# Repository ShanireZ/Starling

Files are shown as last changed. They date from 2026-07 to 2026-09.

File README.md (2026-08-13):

# Starling






Starling v2 是面向 Suzuki GSX250R 车身侧板的电子百叶进气口（“鳃口”）原型：固定框承风、多片叶片由一个舵机联动，开口朝车头迎风，并随车速张合。

## 当前状态

原型一号已经形成可审查的设计包，但尚未完成上板或实车验证：

- [立项文档](docs/charter.md)记录 v2 的范围、失效保护和安全边界。
- [原型一号规格](docs/prototype-v1.md)包含 BOM、接线、台架验证顺序和控制逻辑。
- [参数化 CAD](cad/starling_v1.scad)及其 [打印/装配说明](cad/README.md)是机构的唯一 CAD 来源；`cad/dist/` 为打印交付包。
- [固件骨架](firmware/starling/starling.ino)面向 ESP32 DevKit（WROOM-32），定义了皮托压差测速、舵机控制、被动记录和 USB/蓝牙配置边界；源码明确标注为尚未上板编译验证的骨架。

## 3D 机构演示

[gsx250r-vreal.html](proto/gsx250r-vreal.html) 是唯一现行 3D 演示。可通过本地静态 HTTP 服务器从仓库根目录打开。页面用滑杆模拟车速和百叶开度，并可拖入其他 `.glb`/`.gltf` 模型。页面中的气流效果是机制演示，**不是 CFD 或性能验证**。

## 项目约束

- 设计铁律和当前状态见 [AGENTS.md](AGENTS.md)。
- 断电时机构应由弹簧回到闭合位置；上路前须完成台架、封闭场地和当地法规自查。

## License

本项目自有的代码、文档与素材采用 [GNU General Public License v3.0](LICENSE) 发布。

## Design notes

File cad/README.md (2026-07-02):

# cad/ — 原型一号机构(v0.1 台架版)

> **唯一 CAD 真相 = [`starling_v1.scad`](starling_v1.scad)**(OpenSCAD 参数化源码);`stl/` 全部由源导出,勿手编;`preview/` 为渲染验证图。
> 装 [OpenSCAD](https://openscad.org) 后打开 .scad 即可改参数 → F6 渲染 → 导出 STL(文件底部 `PART` 变量选零件)。
>
> **代打交付包 = [`dist/`](dist)**:带数量的 STL + [`dist/下单说明.txt`](dist/下单说明.txt)(工艺/材料/公差逐件备注)+ 一键上传的 `starling-print-v0.2-pa12.zip`。给打印农场只发 dist,勿发 stl/。
>
> **材料路线(2026-07-02 owner 拍板)**:跳过 PLA 台架批,**直接粉末尼龙一步到位**——MJF/SLS **PA12**(叶片勿加 CF,薄壁要韧性)、框/支架可升 **PA12-CF**;原"台架 PLA → 装车 PETG"路线作废。dist 的 STL 按粉末工艺 `HOLE_COMP=0.1` 导出(FDM 备选须回源码改 0.2 重出);下表"打印姿态/填充"仅对 FDM 备选工艺有意义,粉末工艺无支撑/填充概念。**连带变更:尼龙粘不住 502/CA,装配用胶一律改环氧 AB(粘接面打毛)。**

## 打印清单

| 零件 | 数量 | 打印姿态 | 填充 | 备注 |
|---|---|---|---|---|
| `frame` 固定框 | 1 | 前脸朝下平放 | 30% | 前脸内圈有 3.5mm 悬檐(可加支撑或接受轻微垂坠);轴孔为水平小孔允桥接,打完用 3mm 钻/圆锉轻通 |
| `blade` 叶片 | **4** | 凸面朝下平放 | 100%(薄件) | **两侧翼下需支撑**(弧形底非平面);背脊轴槽朝上,槽内勿生成支撑 |
| `crank` 曲柄 | **4** | 平放 | 100% | 受力小件,实心打 |
| `linkbar` 拉杆 | 1 | 平放 | 100% | |
| `servo_bracket` 舵机支架 | 1 | 板面朝下平放 | 60% | |
| `stand` 台架座 | 1 | 如模型姿态 | 20% | 台架专用,装车不用 |

层高 0.2 / 壁 3 圈(仅 FDM 备选适用)。

## 金属件下料(免焊:剪/锯 + 环氧 AB 胶)

| 料 | 下料 | 用途 |
|---|---|---|
| Ø2 不锈钢轴 | **4 段 × 125mm** | 叶轴(300mm 棒 ×2 根够用) |
| 黄铜管 内2外3 | **8 段 × 6mm** | 轴套,压入框两侧柱孔 |
| M2 螺丝 | 4 颗(≈8mm) | 曲柄销:自攻进曲柄销孔,杆身穿拉杆孔 |
| M2 球头拉杆 | 1 套(杆 ≈25mm 起配) | 舵机臂(8mm 孔位)↔ 拉杆下端孔 |
| M3 自攻 | 2 颗 | 框下双耳 → 台架座立柱 |
| 小扭簧 | 1 只(试配) | 套顶叶轴:一脚插框右柱 Ø2 锚孔,一脚顶曲柄——预紧朝闭合 |

## 装配顺序(台架)

1. 框轴孔压入 8 只黄铜套(紧则用 HOLE_COMP 调大重打框,勿硬敲裂框);
2. 钢轴卡进叶片背脊槽 + 环氧 AB 胶(粘接面砂纸打毛;尼龙粘不住 502/CA),居中(两端各露 ≈12.5mm);
3. 叶片连轴从框内穿入两侧轴套;右侧露出端压上曲柄(过盈 + 环氧胶),**四只曲柄臂必须同角度**(装配时把叶片全部立到竖直位再粘曲柄);
4. M2 螺丝把四只曲柄销接到拉杆四孔(自攻进曲柄,拉杆孔为松孔,能自由转动);
5. 舵机装支架窗口(自带自攻钉),支架用 2×M3 挂框右柱(竖槽可上下微调);
6. 球头拉杆连舵机臂(取 8mm 孔位)与拉杆下端孔,**用易拉夹/球头螺纹把长度调到:舵机中位 ≈ 叶片 50° 半开**;
7. 顶叶轴套扭簧(预紧朝闭合),断电手感验证:松手全组弹回闭合;
8. 框挂台架座(下双耳 M3 自攻进立柱),整机通电跑 `test` 命令扫角。

## 行程与固件映射

- 机械行程:**闭合 = 10°**(微倾使相邻叶鳞片式搭接,不是 0° 纯竖直——纯竖直相邻叶尖会干涉)→ **全开 = 90°(水平)**;
- 固件把 0-100% 开度映射到舵机脉宽 `us0..us90`:**台架标定** `us0` = 叶片抵到闭合位、`us90` = 水平全开位(`set us0 / set us90` + `save`),CLOSED_DEG 的 10° 偏置被标定自然吸收,固件无需改。

## ★ 到货必须卡尺复测的参数(改完重渲重打)

| 参数 | 现值(估) | 说明 |
|---|---|---|
| `SV_HOLE_SPAN` | 34.0 | 舵机两安装孔中心距(**最关键**) |
| `SV_BODY_L / SV_BODY_W` | 28.6 / 13.2 | 舵机体长宽(窗口配合) |
| `SV_AXIS_OFF` | 9.7 | 输出轴距体端偏移 |
| `BUSH_OD / SHAFT_D` | 3.0 / 2.0 | 黄铜套外径 / 钢轴径 |
| `HOLE_COMP` | 源码默认 0.2(FDM);**dist PA12 批以 0.1 导出** | 压入过紧 → 调大 0.1 重出;过松 → 调小 |

## 已验证(2026-07-02)

- 6 件 STL 全部水密(trimesh `is_watertight=True`)、包围盒与设计值一致;
- 正交前视:闭合(10°)四叶满窗遮蔽 / 全开(90°)水平露缝([preview/front_10.png](preview/front_10.png) / [front_90.png](preview/front_90.png));
- 曲柄-拉杆平行四边形联动:侧视 90° 时曲柄水平与拉杆重合、拉杆随销圆弧平移,运动学正确;
- 叶尖扫掠 ±28.9mm vs 内腔 ±30mm,间隙 1.1mm(此项曾按 56 高设计会刮壁,已改 60)。

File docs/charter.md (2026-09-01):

---
type: charter
title: Starling v2 立项文档
---

# Starling v2 立项文档

> **一句话**:装在 GSX250R **车身侧板(车把下整流罩)**上的一对**电子百叶进气口("鳃口")**(固定框 + 联动叶片),**开口朝车头迎风**,随车速开合——越快开得越大,像**张鳃呼吸**纳入迎面气流。**看得见的动态造型件;开口通透后迎风纳气,带来附带的气流 / 散热收益(温和,非主目标)。**

立项日期:2026-06-25 · 名称沿用 Starling(v1 同名项目已废弃重启)

---

## 0. 为什么重启:v1 的教训

v1(摩托车主动空气动力学系统)流产,四个失败点其实是同一个病根的四张脸——**成本前置、收益后置,而收益天花板本来就低**:

| v1 失败点 | 实质 |
|---|---|
| 设计过于复杂,逐渐流产 | 成本无限后拖,从未产出可用切片 |
| 成本 ≫ 收益(仅很小提升) | **真正死因**:250 摩托 <100km/h,主动气动的下压力收益微乎其微 |
| 结构复杂、不便调试观察 | 烧钱过程中看不见盈亏 |
| 过于专业 | 锁死在一个人脑子里,无人能验 |

**复杂本身不是罪,复杂配不上收益才是。** v2 由此立下两道闸:

1. **立项前给收益封顶** —— 性能收益有限,故**以造型 / 动态炫酷为主目标**;鳃口迎风纳气带来的气流 / 散热只当**附带温和收益**,把成本对齐"炫酷"这个可达又可观察的价值,不为微小性能堆复杂度。
2. **第一周就要有看得见的纵切片** —— 用最小可观察实物验证,而非建几个月才发现不值。

---

## 1. 项目身份

- **名称**:Starling(沿用并重释义——椋鸟 / 凤凰,展翅母题)
- **平台**:Suzuki **GSX250R**(单车型起步,非通用支架)
- **形态(2026-06-25 大改 → 百叶式;2026-06-28 定位侧板 + 开口朝车头迎风)**:**车身侧板(车把下整流罩)**上一对**电子百叶进气口("鳃口")**——一个**固定的 U / 矩形结构框**(内凹、NACA 式观感),框内一组**多片联动百叶**,**开口朝车头迎风**。低速齐平闭合,高速叶片张开露缝(战斗机 / F1 多段开缝层叠面的样子)。
- **行为**:**速度越快 → 开度越大**(MCU 按速度驱动百叶角度);开口朝前,张开时像「张鳃呼吸」纳入迎面气流。
- **机构**:固定框承受风载;百叶 = **一个舵机 + 一根连杆带动多片 = 1 个真实自由度**(汽车主动进气格栅 / 空调出风口的成熟做法)。
- **气动姿态(无害优先,收益封顶)**:① **开口朝车头迎风**,低速齐平闭合(最低阻),高速张开像「张鳃呼吸」纳入迎面气流;② 固定框包住叶片边缘(少抖振 / 哨音);③ **后侧通透**(去死后壁、叶片张开气流可从前侧穿过进喉道→入车体内部·借真进气口的观感),**带附带的轻度进气 / 散热作用**,但**不做重型工程化涵道 / 冷却系统**(无独立 airbox·只求开口通透的纳气观感与轻度穿流);高速张开会有少量增阻(迎风口纳气),在 <100km/h、小开口下视为**无害可接受**;**性能非主目标——收益封顶,不为它堆复杂度。**
- **无灯光**:视觉价值 = 这套随速度开合的**动态** + 造型本身。

---

## 2. 定位与价值(收益封顶)

- **价值锚点**:视觉 / 动态炫酷("展翅感"),外行一眼能看懂
- **性能非主目标(收益封顶)**:迎风纳气有附带气流 / 散热收益,但不做气动调优、不堆性能向复杂度
- **场景**:100km/h 以内的日常骑行
- **ROI 闸门**:任何"为多一点性能 / 下压力"的复杂度,默认砍掉

---

## 3. 控制架构(防战线蔓延的生死线)

- **实时控制 100% 板载自包含**:MCU + 传感器,本地决定翼面开度
- **外部连接(蓝牙或有线)只做两件事**:① 配置(模式 / 参数) ② 数据采集与回传
- **外部端(手机 / PC / 网页)不参与实时控制**
- **无云、无 OTA、无跨学科集成**

---

## 4. 设计铁律(v1 四大死因的对策)

1. **收益封顶** — 主价值是造型 / 动态炫酷;迎风纳气的气流 / 散热是**附带温和收益、非目标**;砍掉一切"为性能"的显著复杂度。
2. **第一周可观察纵切片** — 先做出"翼面随某个输入张合"的能看见的最小原型。
3. **单人可造、可调、可调试** — 不引入需专家 / 多人才能维护的结构。
4. **禁战线蔓延** — 无 App 实时控制、无云、无 OTA、无应变片性能反馈链、无多学科集成计划。
5. **外行可读** — 不懂的人看一眼就明白"它随速度展翅,很酷"。

---

## 5. 范围

### ✅ 做(In)
- **机械**:固定 U / 矩形框(兼车头安装支架)+ 多片联动百叶 + 单舵机连杆
- **电子**:板载 MCU + 测速传感 + 供电 + 舵机驱动
- **软件**:板载实时控制逻辑(速度 → 开度)+ 极简配置 / 数据接口(蓝牙或有线)

### ❌ 不做(Out — 明确放弃,守住边界)
- 主动下压力优化 / 闭环气动调参 / 借襟翼追升力
- **重型工程化涵道 / 主动冷却系统**(开口通透有轻度穿流与附带散热,但不做独立 airbox / 热管理)
- 配套 App 实时控制 / 云遥测 / OTA
- 应变片性能反馈链 / 五学科集成计划(v1 的坟墓)
- 灯光

---

## 6. 待裁决(Open Questions — 下一轮立项逐项拍板)

> 刻意保持精简(v1 曾有 28 项启动自检清单——那本身就是病征)。下面是真正卡住设计的少数硬议题。

| # | 议题 | 为什么是硬议题 |
|---|---|---|
| ✅ ~~OQ-1~~ | **作动方式 = MCU 驱动百叶**(舵机按车速设开度) | 已裁决 2026-06-25,随百叶式微调:固定框承受风载、舵机只转小叶片(几乎不吃力);失效保护 = 断电弹回齐平闭合。第一台先做"手动 / 单舵机开合"最小验证 |
| ✅ ~~OQ-2~~ | **平台 = Suzuki GSX250R**(单车型起步) | 已裁决 2026-06-25 |
| ✅ ~~OQ-8~~ | **原型 = 3D 打印**(PLA/PETG;定形后再谈碳板 / 注塑) | 已裁决 2026-06-25 |
| ✅ ~~OQ-9~~ | **形态 = 百叶进气口**(固定 U/矩形框 + 多片联动百叶;低速齐平、高速张开露缝;NACA 内凹观感,非真涵道。**2026-06-28:落车身侧板、开口朝车头迎风**) | **2026-06-25 大改**:由"3 片式折叠成平面"转为百叶式(见 §1)。折叠方案因承风差、舵机顶不住、易抖振而放弃;开口由侧向改迎风见 §7(2026-06-28) |
| ✅ ~~OQ-M~~ | **机构自由度 = 1**(固定框 + 一个舵机经连杆联动全部叶片) | 已裁决 2026-06-25。百叶式把头号复杂度风险一举压到 1 自由度,固定框承风 |
| ✅ ~~OQ-3~~ | **供电 = 先独立电池、后取车电**(原型用充电宝/小 Li 包·零侵入易拆;定形后改带保险丝的附件取车 12V) | 已裁决 2026-06-28。阶段化:第一周可观察优先零侵入 |
| ✅ ~~OQ-4~~ | **测速来源 = 气流压差(皮托管 + 压差传感)** | 已裁决 2026-06-28。板载自包含、不碰车辆系统;主题最契合——迎风口对真实迎面动压开合 |
| ✅ ~~OQ-5~~ | **开度-速度 = 阈值-斜坡曲线 + 失效保护**(低速齐平闭合→过阈值线性张开→高速全开;**全开角硬上限 + 断电弹簧弹回闭合 + 滞回防抖**) | 已裁决 2026-06-28。阈值/斜率具体数值待原型实测调 |
| ✅ ~~OQ-6~~ | **数据 = 丰富采集**(速度/开度/舵机 + 温度/振动/IMU 等),本地存储(+离线回传),**用途 = 为后续版本与其他产品积累数据基础**(R&D 数据集·非本产品性能调优) | 已裁决 2026-06-28。★**守边界(防 v1 性能反馈链复发)**:纯**被动记录·不进实时控制闭环**(实时控制仍只用皮托速度→开度·板载自包含);采数据是副产物非主线、不借此把传感/学科铺开;本地为主、无云实时遥测。落在 §3 允许的"数据采集与回传"内 |
| ✅ ~~OQ-7~~ | **连接 = 有线 USB + 蓝牙 都要**(有线为主:配置/下数据;蓝牙仅免拆配置)。**两者都严守 §3:仅配置 + 数据采集,不碰实时控制、无云、无 OTA** | 已裁决 2026-06-28。蓝牙加 BT 模块但锁死在"非实时控制"边界内防战线蔓延 |
| ✅ ~~OQ-10~~ | **安全/法规 = 低姿态 + 失效闭合 + 本地自查**(工程:低凸出 / 无尖锐边 / 断电弹回闭合静止齐平 / 限位防过张;法规:owner 按当地车检自查突出物·灯光遮挡·噪音;上路前先封闭场地验证) | 已裁决 2026-06-28。鳃口落**侧板**(非车头正前伸入行人路径)风险面更低 |

---

## 7. 状态

- **2026-06-25**:v2 立项启动。地基 3 决策锁定——形态 / 控制 / 名称(沿用 Starling)。仓库与本 charter 建立。
- **2026-06-25**:连续裁决 OQ-1/OQ-2/OQ-8/OQ-9 + 气动逻辑(早先为 3 片式折叠成平面方案)。
- **2026-06-25(形态大改 → 百叶式,已锁定)**:经多轮 3D 推演,**放弃 3 片折叠方案,转为"固定框 + 多片联动百叶"进气口**。理由:折叠方案承风差、舵机顶不住、易抖振。新方案 = **1 自由度**(OQ-M 解决)、固定框承风、低速齐平 / 高速**前缘下斜**张开(消除升力)、**借涵道 / NACA 观感但不做真穿流**。3D 机构示意见 `proto/wing-3d.html`。
- **2026-06-25(暂停于此)**:百叶版形态完整、已存档推送(`proto/wing-3d.html`,commit `40b6733`)。气流方向已厘清——**百叶前缘朝下、正面气流上偏 → 车身微下压力(绝不升力)**;该下压力很小,**不追求**。owner 先歇,后续按 §8 继续。
- **2026-06-26(§8 高仿真第一稿落地)**:owner 拍板"继续推进"→ 新建 `proto/gsx250r-vreal.html`,把示意方块升级为**贴近 GSX250R 车头比例的体块**(全整流罩鼻锥 + 竖排双头灯 + 熏黑风挡 + 前挡泥板 + 前叉 + 前轮/碟盘 + 后视镜),并把**一对百叶进气口落位**到车头两侧真实位置:固定框 + 4 片**有弧度翼型薄片**联动、内凹深腔(借 NACA 观感)、低速齐平 ↔ 高速张开。交互保留(车速→开度滑杆 / orbit / 5 视角预设 / 自动播放)。**验证**:已起静态服务器在真实浏览器引擎中加载——THREE 加载、WebGL 上下文 OK、脚本无异常跑通、滑杆 0→35%→70%→全开→0 readout 正确联动;唯一坑=three.js 的 `Object3D.position` 只读,`Object.assign(mesh,{position})` 必抛 TypeError(已改用 `at()` 助手 `.position.set()`)。**注**:WebGL + 连续 rAF 致无头截图超时,故只做了 DOM/执行级验证;**视觉/比例/叶形美感请 owner 在真实浏览器里眼校**(本稿定位为"比例落位稿",叶形与车漆细节为下一轮精修)。
- **2026-06-26(owner 定角度规格)**:**初始(0 km/h)= 叶片竖直贴面**(0°,齐平封口)、**张开到顶 = 45°**。滑杆 0°→45° 映射。注:"越快开度越大"的**速度→角度曲线属 OQ-5**(慢速是否已到 45°、高速是否更平,待定)。
- **2026-06-26(owner 草图定开合方式:鳃片外掀,非内缩)**:据 owner 手绘 —— 张开时叶片**绕上缘铰链向外掀起、下缘凸出车体表面**(像鳃片 / scoop 张开),露出身后深腔;**不是**往里缩进风道(初版做反)。迎风的外/上表面把正面来风向上导出 → 下压力。代码探针实测全开:下缘 z 由 0.008→**0.107(凸出)**、迎风外法线 Y=**0.707(朝上)**、`protrudesOut & deflectsUp = true`;闭合则前后缘等 z(竖直贴面、中性)。
- **2026-06-26(owner 反馈两项修正,已改)**:第一稿有两处与昨日结论不符,已修——① **百叶开合方向初版做反了**(初版张开是前缘上抬 → 会把风下导=升力,危险)。现已修正为**前缘(下缘)下斜、后缘上抬**:迎面风打在叶片上表面被**向上导出 → 微下压力(绝不升力)**,与 §1/§8 文字一致。代码探针实测开启时下缘在前/在下、上缘在后/在上(`frontLowerAndForward=true`,数值验证非靠截图)。② **风道太浅(薄薄一层)→ 已加深**:风道深度 0.16→**0.42**,内凹腔由后壁 + 上/下/左/右四面内壁组成真实深腔,叶片上缘后掀进风道。
- **2026-06-26(owner 反馈:动效看不清 + 车体太简略 → 转真实建模)**:owner 拍板**车体走路线 A = 导入真实 glTF 模型**。已落地:① **glTF 加载器**(`THREE.GLTFLoader`,jsdelivr UMD):把 `.glb/.gltf` **拖进画面**即加载、或 `?model=URL`;自动缩放居中落地、隐藏占位体块;真车未到位时显示占位体块。**已用 Khronos 样本 GLB 远程验证加载/解析/auto-fit 全通**(`mstatus→已加载`,无报错)。② **百叶动效清晰化**:进气口加大、亮银蓝叶片 + **橙色自由(下)缘描边**(看清哪条缘在动)、深腔更黑拉对比、新增「🔍 进气口特写」视角(默认朝向·NDC 实测右进气口居中 x=0)、滚轮缩放、自动播放放慢 + 两端停顿并默认开启。③ 进气口已独立成 `intakeRig` 组(换真车后整体重定位)。**待 owner**:提供 / 批准一个 GSX250R(或运动摩托)`.glb`(Sketchfab 可下载+CC 过滤,或任意 .glb 拖入);搜索未见干净 CC0 直链 GSX250R。
- **2026-06-26(owner:完全仿真整车 → 收集资料 + 按真实尺寸重建)**:owner 要"车身 / 风道比例 / 后轮 / 完全仿真 GSX,先收集资料建模"。① **收集资料** → 新建 `docs/gsx250r-reference.md`(官方实测:总长 2085 / 宽 740 / 高 1110 / 轴距 1430 / 座高 790 mm;前胎 110/80-17→外半径 304、后胎 140/70-17→外半径 314;17" 十辐;整流罩散热气流逻辑给「鳃口」落位依据)。② **按真实尺寸重建整车**(SPEC 驱动,1 unit=1 m):前后两轮(正确半径/胎宽/轴距)+ 前叉/后摇臂/避震/引擎/排气/油箱/座/尾段/全包整流罩/竖排双头灯/熏黑风挡/前后挡泥板/后视镜/把手;进气口按真实比例落上侧整流罩。**实测对齐**:整车内禀 高 **1.11 m(=真车 1.110 ✓)**、长 **2.05 m(真车 2.085)**、轴距 1.43、落地 y=0;整车默认视角全可见居中、进气口特写 NDC≈(0,0) 居中、百叶机构 `protrudesOut & deflectsUp=true`、无报错。**诚实边界**:手写 three.js = **风格化 CG 非照片级**;照片级仍需拖入真 .glb(加载器已就绪)。
- **2026-06-26(owner:风洞模拟效果,务必真实)**:**诚实边界已言明**——真 CFD(解 N-S/网格/算力)在单文件网页做不到、也超出"视觉件非性能件"的边界;遂做**风洞式气流可视化(示意,非 CFD 解算)**:启发式流场 = 来流 -Z + 车体绕流(Rankine 源-汇)+ 百叶上导(每侧进气口局部上向速度随开度增强);渲染 30 条静态流线(暖色=被明显上导)+ 1400 粒子(live 烟流)+ 测试段框,「🌫 风洞气流」按钮切换、随车速滑杆联动。**数值验证**:右进气口上游流线最高 y 由闭合 1.004 → 全开 **1.169**(+16.5cm 上导),如实呈现"百叶张开→迎面风上导=下压力",随开度增强;WebGL OK 无报错。界面明确标注"非 CFD、仅机制演示非性能验证"(守住不拿气动论证存在意义的红线)。
- **2026-06-26(气动取舍 owner 拍板 B:高速放平低阻,不要下压力)**:讨论后明确——百叶「斜着导流出下压力」与「放平羽化低阻」是**相反叶片角度,不可兼得**;且下压力本就可忽略(~10–15N/<1%车重)、对操控无实感。**owner 选 B**:全开角由 -45° 改 **-90°(水平/顺气流/羽化=低阻通风口)**,高速主打低阻、明确**放弃下压力叙事**。风洞流场同步:偏流强度 = `sin(开度×π)`(0° 与 90° 皆 0、~45° 最大)→ 全速放平流线**顺流穿过不再上挑**。数值验证:右进气口流线最高 y 闭合 1.004 / 中途 1.169 / **全速 1.004(0 偏流=低阻)**。注:阻力最低其实是**闭合齐平**态,任何张开都比闭合多一点阻;"水平"是张开姿态里最省的。
- **2026-06-26(路线 A 落地:真实车体模型接入 + 鳃口落位)**:owner 经 Edge 的 Claude 浏览器插件让我直连看渲染;确认手搓方块车=Minecraft 感天花板,**走真 .glb**。我用浏览器在 Sketchfab 搜到并由 owner 下载 **"Sports Bike" by Futurealiti(CC-BY-4.0)** 放进 `res/sports_bike`(scene.gltf+bin+textures);加载器默认加载它(经静态服务器·`?model=` 可换),`fitModel` 自动缩放居中落地、隐藏占位方块。**鳃口落位**:浏览器实测调出 `GILL_ON_BIKE={iy:0.80,iz:0.78,scale:0.48,spread:0.19,ry:0.45}`(+z=车头),`showModel` 加载后自动把 `intakeRig` 落到前整流罩侧面(headlight 侧颊)。视觉降噪:头灯改小六角、百叶哑光中灰、主光降一档。**已加 CC-BY 署名**(页面 + README + license.txt)。**效果=终于像真车 + 鳃口在前整流罩侧**(虽略凸出曲面)。
- **2026-06-28(修头号缺陷:鳃口被车壳遮挡 → 射线吸附落位)**:owner 反馈「鳃口被车辆模型遮住」。**真因实测**(Edge 的 Claude 浏览器插件 + 本地静态服直连):上一版「收紧落位」(commit `dffdae1`)把鳃口推到 bike-local x≈±0.13,而整流罩**外表面**在该高度位于 x≈±0.25 → 鳃口整体埋进车壳约 0.1m,被红漆整流罩完全遮挡。**改为射线吸附 `snapGillsToModel`**:每侧从车外水平射向中线、命中整流罩外表面 → 鳃口坐落于命中点(略外凸 `proud=0.006` 防 z-fight);换任何 `.glb` 都自动贴合、永不埋没(模型中心线偏移 x≈+0.07 也由逐侧吸附吸收)。**朝向**取表面法线但**压平 Y 分量**——低模整流罩三角面法线常带强下倾(实测开口 ny≈-0.64),直接用会让开口朝下、从侧面看成"贴块";压平后开口只朝侧/前、叶片保持水平。配套:深盒腔→**浅内凹 louvre 面板**(depth 0.7→0.32·薄齐平框 fd 0.07→0.022)、叶片材质回中银蓝防过曝、`focusIntake` 特写改**动态对准**吸附后的右鳃口。**实测结论**:两侧对称落在前整流罩颊面(SUPERSPORT 饰条上方)、闭合=外向封口 / 全开=清晰水平百叶、开度 0→100 联动正常、无 console 报错。新增 `__snap(ay,az,scale,proud)` 控制台实时微调钩子。
- **2026-06-28(owner 草图逐轮定位 → 鳃口落「车把下侧板」、开口「迎风朝车头」·已签收"正确了")**:接上条,owner 用手绘草图 + 标注截图连续校位,最终拍板(均经 Edge 的 Claude 插件直连眼校):① **位置**=从前整流罩颊面下移到**车身侧板**(owner 明确"侧板=车把下面那块板子"=主侧整流罩 `front001` 红面),落在 `GILL_ON_BIKE={ay:0.68, az:0.49}`(右上微调后);② **开口方向**=owner 否掉"朝车侧外",定**「风口与车同向 = 开口朝车头(迎风)」**——改 `snapGillsToModel` 朝向:开口(局部+Z)对齐**车前 +Z**、各侧再略向外张 `cant=0.35`(迎风进气口·两侧对称外张);**位置仍走射线吸附**(命中 front001 侧板表面落位、`proud` 外凸),朝向与落位解耦(法线只管贴面、`cant` 只管开口朝前)。③ scale 0.66。**实测**:闭合=前向封口齐平 / 全开=水平百叶露缝迎风、两侧对称、0→100 联动、无报错;特写视角改前方 3/4(看进迎风口)。`__snap(ay,az,scale,proud,cant)` 加 cant 维度。**页面文案已同步**(去"前缘下斜/侧向羽化"旧叙事)。★**留待 owner**:风洞流场(`fieldVel` 的 IL/IR 上导模型)仍是**旧侧向方案**,与"迎风进气口"不符,且 §1/§8 的气动叙事(前缘下斜/低阻羽化/下压力)是为侧向百叶写的——**迎风进气口的气动故事需重新拍板**(暂不动,默认风洞关)。
- **2026-06-28(迎风进气口气动叙事 + 风洞流场重做·owner 选"迎风口气动叙事+风洞重做")**:既然开口改朝车头迎风,旧"侧向百叶上导=下压力 / 水平羽化=低阻"叙事整套作废,重写:**①气动叙事**(charter 一句话 + §1 形态/气动姿态 + 页面文案)→「**开口朝车头迎风**,低速齐平闭合最低阻,高速张开像**张鳃呼吸纳入迎面气流**;不做真涵道/散热/穿流,高速少量增阻但 <100km/h 小开口无害可接受;不追求下压力/性能」。**②风洞 `fieldVel` 重做**:删"进气口处局部上向速度(defl=sin)"上导模型,改**迎风口纳气=局部汇**(开度越大、离口越近,把迎面气流吸入开口·`draw·6.0·exp(-d²/0.08)`);流线弯入开口(`minD<0.18` 染暖色、`<0.05` 止于口)、粒子被吸入即重生(视觉呼吸);`IL/IR` 移到新迎风口位 `(±,0.68,0.55)`。**数值验证 `__starlingFlowCheck`**:右口上游流线与开口最近距离 闭 0.289 → 0.5 档 0.21 → **全开 0.136**(开度越大越被纳入·单调),Edge 插件实测暖色流线收束入口、无报错。**守红线**:界面标注"非 CFD·机制演示·非性能验证"。
- **2026-06-28(退役旧 `proto/wing-3d.html` → vreal 一本化)**:`git rm proto/wing-3d.html`(轻量方块机构示意·黄灰配色·停留在旧"C 形凤翼/折叠"叙事·曾致 owner 开错文件);README 活链接删除并注明退役。**唯一 3D 真相 = `proto/gsx250r-vreal.html`**。本 §7 内 2026-06-25 历史日志对该文件的引用保留为史(不改写历史)。
- **2026-06-28(按老方式逐项拍板剩余 OQ·第一轮 = 电子/控制 4 项)**:owner 拍板——**OQ-4 测速 = 气流压差(皮托管)**(主题契合迎风口·板载自包含)· **OQ-3 供电 = 先独立电池后取车电**(原型零侵入)· **OQ-5 开度曲线 = 阈值-斜坡 + 断电弹回闭合 + 全开角硬上限 + 滞回防抖** · **OQ-7 连接 = 有线+蓝牙都要**(我原荐只有线·owner 要都要;已锁死蓝牙仅"配置+数据采集"不碰实时控制·守 §3 防战线蔓延)。详见 §6 表。**剩 OQ-6 数据 / OQ-10 安全法规 = 第二轮**。
- **2026-06-28(第二轮 OQ 拍板 = 数据 + 安全法规·★所有 OQ 至此全决)**:owner 拍板——**OQ-6 数据 = 丰富采集**(为后续版本/其他产品积累 R&D 数据集·非本产品性能调优;我原荐最小化·owner 要丰富;**已锁边界:纯被动记录不进实时控制闭环、不借采数据铺学科、本地为主无云遥测**,守住"非性能反馈链") · **OQ-10 安全法规 = 低姿态 + 失效闭合 + 本地自查**。**至此 OQ-1~10 + OQ-M 全部裁决**(§6 表全绿)。
- **2026-06-28(网页修缺陷:鳃口后侧封死 → 后侧通透)**:owner 发现"鳃口后侧封闭、气流无法从前侧穿过叶片"。真因=`makeIntake` 建了**死后壁 + 四面侧壁的封闭盒**,叶片张开后是堵黑墙。修=**去掉后壁**(`back` wall 删)、保留四面暗色喉壁、喉深 mh·0.32→0.5 往车体内部(-Z)延伸 → 叶片张开气流可从前侧穿过进喉道、入车体(借真进气口观感);风洞 `IL/IR` 纳气目标从口面 z0.55 移到**叶片后方喉道内 z0.45** → 气流穿过叶片进入(非停口面),`__starlingFlowCheck` 闭 0.324→全开 0.166(单调)。**Edge 实测**:开口正面看叶片背后是暗喉道纵深(非黑壁)、暖色流线穿叶入喉、无报错。charter §1③ 同步("后侧通透借观感·但仍不做真功能涵道/散热·守非性能件")。(`__view` 视角调试钩复用·留置)
- **2026-06-28(口径软化:不再称"非性能件")**:owner 拍板——鳃口开口通透后**确有迎风纳气的附带气流 / 散热收益(温和)**,故对外**不再称"非性能件 / 视觉件",如实承认附带性能**;但**工程纪律不变**——收益封顶、不为性能堆复杂度、不做重型真涵道 / 冷却系统(防 v1"追微小性能→堆复杂度→流产"重演)。本 charter 规范段(一句话 / §1③ / §2 / §4铁律1 / §8)已据此软化措辞;§7 早期历史日志的"非性能件"表述保留为史。
- **2026-07-02(原型一号规格落地:硬件选型四拍板 + BOM/接线图/固件骨架)**:按老方式一轮拍板硬件选型——**主控 = ESP32 DevKit(WROOM-32)**(内置蓝牙满足 OQ-7 免外挂模块·USB 即有线口)· **测速 = MS4525DO 数字 I2C 空速计模块**(owner 否掉我推荐的 MPXV7002DP 模拟件,选数字免 ADC 噪声、低速端更稳——阈值点 ~20km/h 动压仅 ~19Pa)· **舵机 = 17-25g 迷你金属齿数字舵**(owner 主动问中间档后选定,EMAX ES3054 级;买摩托振动环境耐久裕量,风载折算力矩仅 ~0.3kg·cm)· **数据 = 标准包+GPS**(MPU6050+BMP280+DS3231+microSD+NEO-6M;GPS 对地速度给皮托标定当参照,契合 OQ-6 R&D 数据集)。产出三件套:**`docs/prototype-v1.md`**(纵切片成功判据·BOM 合计约 ¥320-480·供电预算·机构规格[框 120×70mm/4 片 cambered 叶/钢丝拉杆联动/扭簧常闭 ≤0.5kg·cm/行程 0→90° 硬+软双限位]·固件设计·六步装配验证清单)+ **`docs/img/wiring-v1.svg`**(接线图;★MPU6050 AD0→3V3 改 0x69 避开 DS3231 的 0x68 地址冲突·舵机 5V 主轨直供+≥470µF·全系统共地·充电宝须选无小电流自动断电款)+ **`firmware/starling/starling.ino`**(固件骨架·未上板编译:状态机 BOOT→ZERO_CAL→RUN⇄FAULT;控制律 压差→IAS→阈值-斜坡+滞回+限斜率+0-90° 限位→舵机 LEDC;SD 10Hz CSV 纯被动记录;USB/蓝牙同一命令台,`test` 仅 IAS<5km/h 台架可用·无 OTA·守 §3)。
- **2026-07-02(采购清单零烙铁审核 → xlsx 执行版)**:owner 新约束 = **零烙铁**(不做任何锡焊,需焊接的一律走网上打板+贴片/插件焊)。全面复审 BOM 出 **`res/prototype-v1-采购清单.xlsx`**(台架 37 项含全部辅材·必买约 ¥615/全部 ¥826·阶段二装车页·说明与 PCB 方案页;Excel 重算零公式错误)。关键增补:模块一律选**已焊排针**发货、**MS4525 套装标配 JST-GH 座须配 GH 转杜邦线**(查证 Holybro/3DR 规格:含 PT40 皮托管+40cm 软管+GH4P 线·±1psi/14 位/0.84Pa)、DS3231 须 **LIR2032 充电版**、新增 **ESP32 38Pin 端子扩展板**(免焊+抗振+解决面包板盖孔)、机构联动改 **M2 球头拉杆+易拉夹**、舵机 **EMAX ES3054 查证坐实**(17g 数字金属齿双轴承 3.5kg·cm@6V 行程 145°/700-2300µs)。**PCB 拍板级结论**:台架阶段不打板(免焊三原则可 100% 跑通);装车阶段做**模块底板**(嘉立创贴片+插件焊·排母插模块·约 ¥90-150),**不做芯片级全集成**(MS4525 芯片难购/一次成板风险/违背第一周可观察)。
- **2026-07-02(机构 CAD v0.1 落地:6 件 3D 打印 STL + 装配文档)**:winget 装 OpenSCAD,出**参数化源码 `cad/starling_v1.scad`**(唯一 CAD 真相·所有关键尺寸参数区·舵机/轴径等到货卡尺复测后改参重渲)+ 6 件 STL(`cad/stl/`:固定框/叶片×4/曲柄×4/拉杆/舵机支架/台架座)+ `cad/README.md`(打印姿态/金属下料表/8 步装配/标定与复测清单)。**机构方案**=威尼斯百叶中轴转(Ø2 钢轴入叶背脊槽+CA·黄铜套内衬框孔)+ 平行四边形联动(四曲柄 R8 + 拉杆 M2 销 + 舵机第五曲柄经球头短杆可调)+ 顶叶轴扭簧常闭。**两处落地修正**:①闭合角=**10° 微倾鳞片搭接**(纯竖直 0° 相邻叶尖干涉——弦 15>轴距 14;固件 us0 标定自然吸收);②内腔高 56→**60**(叶尖扫掠 ±28.9 需间隙)。**验证**=6 STL 全水密(trimesh)+包围盒符合;正交渲染:闭合满窗遮蔽/全开水平露缝/曲柄拉杆随动正确(`cad/preview/front_10|front_90.png`)。
- **2026-07-02(打印材料改线:owner 拍板直接全上 PA12(-CF) 粉末尼龙·跳过 PLA 台架批)**:owner 问"为何不用 PA-CF/PA12-CF(国内代打便宜)"——评估后认账两点(MJF PA12 代打确实白菜价 ~¥60-120 全套;装车件 PA12-CF 全面优于原定 PETG),原"台架 PLA → 装车 PETG"两步路线作废。**材料分配**=叶片 PA12 **勿加 CF**(2mm 薄壁要韧性,CF 填充偏脆)、框/支架/曲柄/拉杆可 PA12-CF。**连带变更三项**:①装配胶 502/CA → **环氧 AB**(尼龙表面能低 CA 粘不住;采购清单已加行,必买合计 ¥625)②dist STL 以粉末工艺 **HOLE_COMP=0.1** 重出(FDM 备选回 0.2)③下单说明 v0.2 按 MJF/SLS 重写(无支撑/填充概念·清粉提示·FDM 备选段保留)。**下单前置**=舵机/轴/套到货卡尺复测改参重出 STL 再传农场(05 支架尤其;急打可先去掉 05)。
- **下一步**:① **按 `res/prototype-v1-采购清单.xlsx` 台架页下单**(owner) · ② ~~机构 CAD 建模~~(✅ 2026-07-02 已出 `cad/`,剩:舵机等到货复测 SV_* 参数后打印) · ③ 元件到货后按规格 §6 六步装配验证(面包板测速链 → 舵机控制链 → 数据链 → 打印机构 → 整机台架) · ④ 网页收尾(可选·待定):默认远景偏暗 / 鳃口偏小是否提亮取景;若要更像 GSX250R 可换专门车型 .glb。

---

## 8. 后续网页模型计划(GSX250R 高仿真 · 待 owner 拍板启动)

下一轮的网页 3D 不再是示意方块,而是**贴近真实 GSX250R 的高仿真**,目标"看着就像装在真车上"。要做的:

1. **真车替换**:用接近 GSX250R 的车头 / 整流罩 / 前轮比例替换当前占位方块(找参考图 / 三视图对齐尺寸)。
2. **进气口落位**:把一对百叶涵道安到车头两侧的真实位置,尺寸与车头比例协调。
3. **叶片 / 涵道精修**:
   - 叶片做成有弧度(cambered)的翼型薄片而非平板;**前缘朝下**(气流上偏 → 下压力侧,不升力);
   - 涵道做出 NACA 式内凹深腔的真实观感(借观感、非真穿流);
   - 片数 / 缝距 / 开度行程按视觉与"1 自由度联动"定。
4. **交互保留**:车速 → 开度滑杆、鼠标 orbit、视角预设;低速齐平 ↔ 高速张开。
5. **材质 / 配色**:贴近真实(车漆 + 金属框 + 叶片),出一版能直接看效果的渲染。
6. **守住的约束**:1 自由度;固定框承风;造型为主、性能为辅(收益封顶,不堆性能复杂度);不做重型真涵道 / App / 云。

**启动条件**:owner 拍板后开做(可一次出 v-real,或先粗模对比例再精修)。

**进度(2026-06-26)**:已落地**第一稿 = 比例落位粗模**(`proto/gsx250r-vreal.html`),完成上表 1/2/4/6(真车比例体块替换 + 进气口落位 + 交互保留 + 守住约束),3(叶片/涵道精修)做了基础版(4 片 cambered 翼型薄片 + 深内凹腔),5(材质/配色)出了车漆蓝基础版。**owner 反馈后已修两项**:百叶开合方向(前缘下斜/迎面风上导出/下压力,初版方向做反已纠正)+ 风道加深(0.16→0.42 真实深腔)。**待 owner 眼校后**继续 3/5 的精修:对齐真车三视图尺寸、叶形与缝距按视觉定稿、出可直接看效果的渲染。

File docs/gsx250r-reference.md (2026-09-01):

---
type: reference
title: GSX250R 建模参考资料
---

# GSX250R 建模参考资料

> 为 §8「完全仿真整车」收集的真实尺寸 / 比例底本。建模一律以此为准(单位:mm,three.js 场景按 m)。
> 收集日期:2026-06-26 · 来源见文末。

## 1. 整车尺寸(官方 / 规格站一致)

| 项 | 值 | 备注 |
|---|---|---|
| 总长 Overall length | **2085 mm** | 前轮最前 → 车尾最后 |
| 总宽 Overall width | **740 mm** | 多为后视镜 / 把手宽 |
| 总高 Overall height | **1110 mm** | 地面 → 风挡 / 镜顶 |
| 轴距 Wheelbase | **1430 mm** | 前后轮中心距(核心比例锚) |
| 座高 Seat height | **790 mm** | |
| 最小离地 Ground clearance | **≈165 mm** | 规格站未统一,取常见值,待官方手册校 |
| 整备质量 Curb weight | **181 kg** | |
| 发动机 | 248cc 并列双缸水冷 | 仅作体块参考 |

## 2. 车轮 / 轮胎(前后都要,后轮此前缺)

| | 轮胎规格 | 胎宽 | 胎壁 | **外半径** | 外径 |
|---|---|---|---|---|---|
| 前 Front | **110/80-17** | 110 mm | 110×0.80=88 mm | **≈304 mm** | 608 mm |
| 后 Rear | **140/70-17** | 140 mm | 140×0.70=98 mm | **≈314 mm** | 628 mm |

- 17" 轮辋直径 = 17×25.4 = **431.8 mm**(半径 215.9 mm);外半径 = 215.9 + 胎壁。
- 轮型:**十辐铸铝**(10-spoke cast aluminium),IRC 轮胎。
- 部分年份(2023)后胎为 **140/55-17**(胎壁 77 → 外半径 ≈293 mm)。本项目主用 **140/70-17**。

## 3. 整流罩 / 散热气流(给「鳃口」落位的真实依据)

- 全包整流罩(full fairing),GSX-R 家族造型语言:竖排双头灯 + 尖鼻锥 + 熏黑风挡。
- 官方描述:整流罩**导冷风进水箱、把热风带离骑手**——即真车侧整流罩本就有进 / 出风功能区。
- → Starling「电子百叶鳃口」的真实落位 = **上侧整流罩 / 头灯侧下方的侧颊面**(视觉显眼,又贴近真车散热区逻辑);非车头正脸。

## 4. 建模坐标 / 比例(three.js 场景,单位 m,1 unit = 1 m)

坐标系:**+Z = 车头朝前**,+Y = 上,+X = 右。以两轮中心连线中点为原点附近布局。

| 部位 | 位置(z, y) | 尺寸 | 来源 |
|---|---|---|---|
| 前轮中心 | z=+0.715, y=0.304 | 外半径 0.304,胎宽 0.110 | 轴距/2;前胎 |
| 后轮中心 | z=-0.715, y=0.314 | 外半径 0.314,胎宽 0.140 | 轴距/2;后胎 |
| 车头最前 | z≈+1.019 | — | 前轮中心 + 前胎半径(总长校验) |
| 车尾最后 | z≈-1.066 | — | 总长 2.085 − 前段 |
| 座面 | y≈0.790 | — | 座高 |
| 油箱顶 | y≈0.88–0.92 | — | 估(座高之上一拳) |
| 风挡顶 / 总高 | y≈1.110(车头处) | — | 总高 |
| 转向头 / 三角台 | z≈+0.66, y≈0.95 | — | 估,前叉上端 |
| 前叉倾角 | ≈25–26°(rake) | — | 同级运动车常见值 |

> 校验:总长 = 前胎最前(1.019) − 车尾(−1.066) = **2.085 m ✓**;轴距 = 0.715−(−0.715) = **1.430 m ✓**。

## 5. 待补 / 存疑

- 离地间隙、前叉精确 rake/trail、把宽、尾段精确长度 —— 规格站缺,需**官方用户手册 PDF** 或**三视图蓝图**精校(见来源)。
- 三视图蓝图:3DModels.org / the-blueprints.com 有 GSX250R 蓝图,可作侧影对齐底图(注意授权,仅作比例参考)。

## 来源

- [Suzuki GSX250R — Wikipedia](https://en.wikipedia.org/wiki/Suzuki_GSX250R)
- [Global Suzuki — GSX250R 产品页](https://www.globalsuzuki.com/motorcycle/smgs/products/2024gsx250r/)
- [Torquepedia — GSX250R 规格](https://www.torquepedia.com/suzuki/gsx250r/2024)
- [UltimateSpecs — GSX250R 技术规格](https://www.ultimatespecs.com/motorcycles-specs/suzuki/suzuki-gsx250r-2019)
- [Webike Japan — GSX250R 规格](https://japan.webike.net/SUZUKI/GSX250R/13840/m-spec/)
- 蓝图:[3DModels.org — GSX250R 2023 Blueprint](https://3dmodels.org/blueprints/suzuki-gsx250r-2023-blueprint/) · [the-blueprints.com — Suzuki](https://www.the-blueprints.com/blueprints/motorcycles/suzuki/)

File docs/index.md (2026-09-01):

---
okf_version: "0.2"
---

# Starling 文档

* [agents/](./agents/index.md)
* [Starling v2 立项文档](./charter.md)
* [GSX250R 建模参考资料](./gsx250r-reference.md)
* [Starling 原型一号规格(prototype v1)](./prototype-v1.md)

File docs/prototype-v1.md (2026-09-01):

---
type: reference
title: Starling 原型一号规格(prototype v1)
---

# Starling 原型一号规格(prototype v1)

> 2026-07-02 · 依据:charter §6 全部 OQ 裁决 + 本日硬件选型四拍板(见附录 A 决策记录)。
> **一句话**:一套台架上就能跑起来的最小实物——对皮托管来风,百叶像鳃一样张开;风停,弹簧把它合回齐平。

---

## 0. 目标与纵切片(第一周可观察)

原型一号**不追求装车**,追求"看得见地跑通全链":

```
迎面气流 → 皮托管 → MS4525DO 压差 → ESP32(阈值-斜坡曲线) → 舵机 → 连杆 → 多片百叶张合
                                    ↘ 传感器套餐 → microSD 日志(纯被动记录)
                                    ↘ USB / 蓝牙 → 配置与取数(不碰实时控制)
```

**成功判据(台架)**:
1. 对皮托管吹气(吹风机/骑车慢速手持),百叶随"风速"张开;停风后回到齐平闭合;
2. 拔电源,叶片被扭簧弹回闭合(失效保护实测);
3. SD 卡里有一段完整 CSV 日志(时间戳/压差/速度/开度/IMU/GPS);
4. 手机蓝牙或 USB 串口能改阈值参数并保存,重启后生效。

---

## 1. BOM 清单

| # | 类别 | 器件 | 关键规格 | 用途 | 参考价(¥) |
|---|---|---|---|---|---|
| 1 | 主控 | **ESP32 DevKit(WROOM-32)** | 双核 240MHz·内置蓝牙+WiFi·USB 串口 | 实时控制 + 配置口(蓝牙免外挂,OQ-7) | 25 |
| 2 | 测速 | **MS4525DO 空速计模块 + 皮托管套装** | 数字 I2C(0x28)·14 位·含皮托管与软管 | 皮托压差 → 速度(OQ-4) | 150~230 |
| 3 | 作动 | **17-25g 迷你金属齿数字舵机** | EMAX ES3054 级(17g/3.5kg·cm)或 JX 同级 | 单舵机连杆联动全部叶片(1 自由度) | 30~60 |
| 4 | 数据 | MPU6050 模块(GY-521) | I2C **0x69(AD0→3V3)** | 振动 / 姿态记录 | 6 |
| 5 | 数据 | BMP280 模块 | I2C 0x76·3V3 | 气温 / 气压(环境参照) | 5 |
| 6 | 数据 | DS3231 RTC 模块 | I2C 0x68·带纽扣电池 | 日志真实时间戳 | 8 |
| 7 | 数据 | microSD SPI 模块 + 16GB 卡 | 3.3V 直连型·FAT32 | 本地日志(OQ-6) | 15 |
| 8 | 数据 | NEO-6M GPS 模块(GY-GPS6MV2) | UART 9600·含天线 | 对地速度/轨迹(皮托标定参照) | 25 |
| 9 | 供电 | USB 充电宝 5V ≥2A | **选无小电流自动断电款** | 独立电池·零侵入(OQ-3 阶段一) | 已有/50 |
| 10 | 机构 | PETG/PLA 打印料 | PETG 优先(耐热日晒) | 固定框 / 叶片 / 摇臂 | 已有 |
| 11 | 机构 | 扭簧(小规格若干试配) | 回位力矩 ≤0.5kg·cm 级 | 断电弹回闭合(OQ-5) | 10 |
| 12 | 机构 | 连杆/销轴五金 | 1.5~2mm 钢丝拉杆·M2 螺丝·黄铜管轴套 | 叶片联动 | 20 |
| 13 | 电气杂项 | 杜邦线·XH2.54 接头·热缩管·≥470µF 电解电容·面包板 | — | 接线 | 20 |
| | | | | **合计** | **约 320~480** |

后期装车追加(本轮不买):12V→5V 降压带保险丝(取车电,OQ-3 阶段二)。

> **采购执行版(2026-07-02 零烙铁审核)**:[`res/prototype-v1-采购清单.xlsx`](../res/prototype-v1-采购清单.xlsx) —— 含全部辅材(线缆/胶枪/端子/轴材等 37 项)、数量与备件策略、淘宝搜索词、免焊要点;台架页必买合计约 ¥615(全部 ¥826)。关键增补:模块一律选**已焊排针**发货、空速计套装标配 **JST-GH 座须配转杜邦线**、DS3231 须 **LIR2032 充电版**(CR2032 要拆电阻=焊接活)、新增 **ESP32 38Pin 端子扩展板**、机构联动改 **M2 球头拉杆+易拉夹**(免弯钢丝)。**PCB 结论**:台架阶段不打板(全免焊可跑通);装车阶段做**模块底板**(嘉立创贴片+插件焊,排母插模块),不做芯片级全集成(详见 xlsx「说明与PCB方案」页)。

---

## 2. 接线

接线图

| ESP32 引脚 | 接 | 说明 |
|---|---|---|
| GPIO21 / GPIO22 | I2C SDA / SCL | 总线挂 MS4525DO(0x28)、MPU6050(0x69)、BMP280(0x76)、DS3231(0x68) |
| GPIO18/19/23/5 | microSD SCK/MISO/MOSI/CS | VSPI |
| GPIO17 / GPIO16 | GPS RX / TX(交叉) | UART2,9600bps |
| GPIO13 | 舵机信号 | LEDC 50Hz PWM |
| VIN / GND | 5V 主轨 / 共地 | 充电宝 USB 剥线或用 USB 分线板 |

**四条硬注意**(接错最常见的坑):
1. **MPU6050 的 AD0 必须接 3V3** → 地址变 0x69,否则与 DS3231 的固定地址 0x68 冲突,总线读乱;
2. MS4525DO 用 5V 供电,I2C 开漏、总线上拉 3.3V(模块自带上拉即可),与 ESP32 直连安全;
3. **舵机电源直取 5V 主轨**,不要走 ESP32 板载稳压(堵转瞬间电流会把主控拉复位),就近并 ≥470µF 电容;全系统共地;
4. 皮托管装在**车头迎风干净气流处**(台架阶段手持即可),动压/静压两根软管别接反(接反 = 读数永远为负,固件会视为 0)。

---

## 3. 供电预算

| 负载 | 典型 | 峰值 |
|---|---|---|
| ESP32(蓝牙开) | 120mA | 250mA |
| 舵机(17-25g 数字) | 10mA 静置 | 600~800mA 堵转瞬间 |
| GPS + 传感 + SD | 70mA | 120mA |
| **合计** | ~200mA | **<1.2A** |

5V/2A 充电宝裕量充足。**坑**:多数充电宝负载 <100mA 数分钟后自动断电——买标注"支持小电流/手环模式"的,或接一个小负载保活;断电不危险(弹簧回闭合),但日志会断。

---

## 4. 机构规格(3D 打印,下一步出 CAD)

- **固定框**:外框约 **120 × 70mm**、梯形/矩形 U 框(承全部风载),背面通透(charter §1③),框缘包住叶片边缘防哨音;带侧板安装耳。
- **叶片**:**4 片**,约 100 × 15mm,cambered 薄翼型截面(与 3D 演示一致),中轴销转动(威尼斯百叶式),两端黄铜管轴套。
- **联动**:每片叶带同长曲柄,一根钢丝拉杆串联全部曲柄,舵机摇臂驱动拉杆 = **1 个真实自由度**(OQ-M)。
- **行程**:**0°(竖直齐平闭合)→ 90°(水平全开)**;两端打印硬限位块,固件再叠软限位(双保险)。
- **失效保护**:扭簧装在其中一片叶轴上、预紧朝闭合方向;舵机通电顶开、断电松劲 → 弹簧带动整组连杆回闭合。弹簧回位力矩 ≤0.5kg·cm(舵机 3.5kg·cm 裕量 7 倍;先买几个小规格试配)。
- **材料**:台架 PLA 快速迭代;装车件换 **PETG**(耐热日晒)。
- **风载参考**:100km/h 动压 ~470Pa,4 片叶总受风面 ~0.006m² → 总力 ~3N,折算轴力矩 ~0.3kg·cm——舵机与簧都远够。

> **CAD 已落地(2026-07-02)**:参数化源码 [`cad/starling_v1.scad`](../cad/starling_v1.scad) + 6 件 STL([`cad/stl/`](../cad/stl))+ 渲染验证图([`cad/preview/`](../cad/preview));打印/下料/装配/标定说明见 [`cad/README.md`](../cad/README.md)。注意两处与上文的落地修正:**闭合角 = 10° 微倾**(纯竖直相邻叶尖干涉,鳞片式搭接;固件标定 `us0` 自然吸收)、**内腔高 56→60**(叶尖扫掠间隙)。

---

## 5. 固件设计(骨架见 [`firmware/starling/starling.ino`](../firmware/starling/starling.ino))

**状态机**:

```
BOOT(外设自检) → ZERO_CAL(静止 2s 压差零偏校准) → RUN(50Hz 控制环)
                                                     ↕(传感连续失败 25 次 / 恢复)
                                                    FAULT(舵机回 0° 闭合·继续日志·周期重试)
```

**控制律(每 20ms)**:压差 q(减零偏) → IAS = √(2q/1.225) → EMA 滤波 → **阈值-斜坡曲线 + 滞回**(v>V_ON 才起开;回落到 V_ON−HYST 以下才归零) → **限斜率**(SLEW°/s 防抖动) → **0~OPEN_MAX 硬限位** → 舵机脉宽。

**默认参数**(NVS 持久化,全部可经配置口改;数值待台架/路测标定,OQ-5):

| 参数 | 默认 | 含义 |
|---|---|---|
| V_ON | 20 km/h | 开始张开阈值 |
| V_FULL | 60 km/h | 全开速度 |
| HYST | 3 km/h | 关闭滞回 |
| OPEN_MAX | 90° | 全开角硬上限 |
| SLEW | 120°/s | 开度变化限斜率 |
| SERVO_US_0 / _90 | 1000/2000µs | 闭合/全开脉宽(装配后标定) |
| LOG_HZ | 10 | 日志频率 |

**日志**(microSD,CSV,10Hz):`ms, 日期时间(RTC), q_pa, ias_kmh, open_pct, servo_deg, ax/ay/az/gx/gy/gz, imu_temp, baro_pa, baro_temp, gps_fix/lat/lon/spd_kmh` —— 纯被动记录,不进控制闭环(OQ-6 边界)。

**配置口**(USB 串口与蓝牙 SPP 共用同一命令台,115200):`help / stat / get / set k v / save / cal / log on|off / test <deg> / reboot`。
**§3 边界锁死**:`test`(手动摆舵)**仅在 IAS < 5km/h 时接受**(纯台架用途);无 OTA;蓝牙仅配置+取数,任何"外部端实时控制开度"的功能一律不做。

---

## 6. 装配与验证步骤(按序,每步可观察)

1. **面包板电气链**:ESP32 + MS4525DO,串口打印 q 与 IAS,对皮托管吹气看数值 → 证测速链;
2. **加舵机**:吹气 → 舵机摆角随"风速"走曲线 → 证控制链(此时即是"翼面随输入张合"的最小纵切片);
3. **加齐传感套餐 + SD**:跑 10 分钟拿到完整 CSV → 证数据链;蓝牙/USB 改参数存取 → 证配置链;
4. **打印机构**:框+叶+连杆装配,手推顺滑无卡滞 → 挂舵机联动 → 挂扭簧,断电弹回实测;
5. **整机台架**:吹风机全链演示(= §0 成功判据);
6. 之后才谈装车:侧板安装耳适配、皮托走线、封闭场地试跑(OQ-10)。

---

## 7. 安全与失效(呼应 OQ-5 / OQ-10)

- 断电/固件跑飞 → 舵机松劲 → 扭簧弹回齐平闭合(静止态 = 最低阻、最低姿态);
- 机械硬限位 + 固件软限位双保险,叶片永不越 0~90° 行程;
- 无尖锐外缘,框缘包叶;装车阶段按 OQ-10 做当地车检自查与封闭场地验证。

---

## 附录 A · 硬件选型决策记录(2026-07-02,老方式一轮拍板)

| 议题 | 我的推荐 | owner 拍板 | 备注 |
|---|---|---|---|
| 主控 MCU | ESP32 DevKit | **ESP32 DevKit** ✓ | 内置蓝牙满足 OQ-7 免外挂 |
| 压差传感 | MPXV7002DP 模拟(便宜够用) | **MS4525DO 数字 I2C** ✗推荐被否 | owner 选数字件:免 ADC 噪声、低速端更稳(阈值点 ~20km/h 仅 ~19Pa) |
| 舵机 | MG90S → 追问中间档后荐 MG92B | **17-25g 迷你金属数字舵** | owner 主动要中间档(EMAX ES3054 级),买摩托振动环境耐久裕量 |
| 数据套餐 | 标准包(IMU+气压+RTC+SD) | **标准包 + GPS** | GPS 对地速度给皮托标定当参照,契合 OQ-6 R&D 数据集 |

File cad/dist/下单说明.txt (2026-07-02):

================================================================
Starling 原型一号 机构件 3D 打印下单说明(v0.2 · PA12 尼龙批)
日期:2026-07-02
================================================================

★★ 下单前置条件(先别急着传文件)★★
本包 STL 的舵机相关尺寸(05 支架)与轴孔配合仍是估值。
正确顺序:等舵机/黄铜管/钢轴到货 → 卡尺复测 → 回源码改参重出 STL → 再下单。
若急着先打,可去掉 05 支架单独后补,其余 5 件风险很低。

【工艺 / 材料】
- 首选:MJF(HP 多射流熔融)或 SLS 粉末尼龙。
- 材料分配:
  * 02 叶片 ×4:PA12(不加碳纤——薄壁件要韧性,CF 填充反而偏脆)
  * 01 框 / 03 曲柄 / 04 拉杆 / 05 支架:PA12 即可;预算宽裕可升 PA12-CF(更刚更耐热)
  * 06 台架座:PA12(无要求,怎么便宜怎么来)
- 颜色:MJF 本色灰或染黑均可。
- 备选:若走 FDM PA12-CF/PA-CF 线材工艺,见文末【FDM 备选说明】。

【通用要求(重要)】
1. 单位 mm,按 1:1 打印,勿缩放、勿镜像。
2. ★孔径已按粉末工艺含 +0.1mm 补偿:请勿再做孔补偿、勿扩孔,
   小孔(Ø2-Ø3.3)略紧是设计预期(要压入金属轴套/自攻螺丝)。
3. 粉末工艺无需支撑与摆放要求,农场自行排产即可;实心打印(无填充概念)。
4. 尺寸公差按农场标准(±0.3% 级)即可,无特殊精度要求。
5. 清粉注意:02 叶片顶部有 2.1mm 长条小槽、各件有 Ø2 级小孔,请清粉通透。

【逐件清单】
----------------------------------------------------------------
文件                       数量    材料          备注
----------------------------------------------------------------
01_frame_x1.stl             1     PA12/PA12-CF  120x70x25 主框(含四耳 144x94)
02_blade_x4.stl             4+1备  PA12(勿CF)   弧形薄叶片;顶部 2.1mm 槽清粉通透
03_crank_x4.stl             4+2备  PA12/PA12-CF 中心孔 Ø2.05、臂端孔 Ø1.8,勿扩
04_linkbar_x1.stl           1+1备  PA12/PA12-CF 小拉杆
05_servo_bracket_x1.stl     1     PA12/PA12-CF ★依赖舵机实测尺寸,建议复测后再打
06_stand_x1.stl             1     PA12         台架底座,无精度要求
----------------------------------------------------------------

【验收标准(给自己,收货时核对)】
- 框侧 Ø3.1 孔:能压入外径 3mm 黄铜管(手压略紧为正;过松改用环氧胶固定)。
- 叶片背脊槽:2mm 钢丝能卡入到底。
- 曲柄中心孔:2mm 钢轴能压入(过盈)。
- M2 螺丝能自攻进曲柄臂端孔(尼龙自攻手感偏韧,正常)。
- 叶片平放目测无明显翘曲(< 0.5mm)。

【装配用胶注意(换材料的连带变更)】
尼龙表面能低,502/CA 胶粘不住 PA12!
钢轴粘叶片槽、曲柄固定轴端 → 一律改用环氧 AB 胶(5 分钟型即可),
粘接面先用砂纸打毛。此项已加入采购清单。

【尺寸速查(报价核对)】
frame 144x94x25 / blade 100x15x6 / crank 7x14.5x3
linkbar 8x70x3 / servo_bracket 26x74x3 / stand 170x60x45
全套实体体积约 126 cm³(PA12 密度 1.01,全实心约 130g)。

【FDM 备选说明(仅当农场无粉末工艺时)】
- 材料 PA12-CF 线材;STL 已按打印姿态摆好落床,按现姿态打。
- 层高 0.2 / 壁 >=3;叶片两翼下加支撑(槽内勿生成支撑);
  框前脸内圈 3.5mm 悬檐可加支撑或接受轻微垂坠。
- FDM 孔收缩比粉末大:若压入过紧属正常,回源码把 HOLE_COMP 调回 0.2 重出。

【源文件】
参数化源码与装配说明见仓库 cad/ 目录(starling_v1.scad + README.md);
本批 STL 由源码以 HOLE_COMP=0.1(粉末工艺)导出;尺寸修改一律回源码改参重导。

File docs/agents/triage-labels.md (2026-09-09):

---
type: convention
title: Agent skill triage labels
description: The five canonical engineering-skill triage roles map to no published label here; say the triage judgement in the issue instead.
tags: [agents, triage]
status: stable
---

# Triage Labels

技能用五个 canonical triage 角色说话。本文件回答的是：**技能说「打上那个标签」时，这里到底该做什么。**

## 映射：四个角色没有标签可打

| Label in mattpocock/skills | Label in our tracker | Meaning |
| --- | --- | --- |
| `needs-triage` | **（不发布）** | Maintainer needs to evaluate this issue  |
| `needs-info` | **（不发布）** | Waiting on reporter for more information |
| `ready-for-agent` | **（不发布）** | Fully specified, ready for an AFK agent  |
| `ready-for-human` | **（不发布）** | Requires human implementation |
| `wontfix` | `wontfix` | Will not be actioned |

★ `wontfix` 能用，是因为它本来就是 GitHub 的默认标签之一 —— **不是有人为 triage 建的**。

## 技能提到某个 triage 角色时怎么办

**把那个判断写成 issue 正文或评论里的一句话**，连同判断的依据。
读 issue 的人和下一个 agent 都读得到它，而一个没发布的标签他们读不到。

⛔ **不要临时 `gh label create` 一个再打上去。** 那样每个仓会长出各自拼法的一套词汇
（`ready-for-agent` / `ready_for_agent` / `agent-ready`），而**没有任何东西在对齐它们**。
要发布，走下面「某个项目真要用标签时」。

## 2026-09-09 的实测读数（⛔ 别重跑这趟调查）

| 量的东西 | 结果 |
|---|---|
| 18 个可达仓里这四个标签的数量 | **0**（`gh label list` 逐仓扫） |
| 各仓实际标签 | 9 个 GitHub 默认；`Plumbline` / `PubEnvCtl` / `RootPage` 另有 `accessibility` |
| 本文件的副本份数 | **19**（每个项目 `docs/agents/` 各一份） |
| 其中仍是模板原样的 | **18 份逐字节相同** |
| 唯一改过的那份 | `Plumbline`，**只改了末句**、映射一个字没动 |

★★★ **值得记的不是「没人建标签」，是这份模板 19/19 全没填过。**
它原来的末句是「Edit the right-hand column to match whatever vocabulary you actually use」——
一句从来没有人执行过的指令，读起来却完全像一条正常的约定。

⛔ **未采纳「把四个标签建到 19 个仓里让文档变真」**：找不到任何消费方。
那正是本工作区栽过两次的形状 —— **声明了却没有人接**
（BetaPass 的 prune 单测全绿只证明「调用它会删对行」，不证明「有人调用它」；betai 的 D133 同理）。

## 某个项目真要用标签时

1. `gh label create` 真的建出来，**建完当场 `gh label list` 复核**；
2. 改**那个项目自己的** `docs/agents/triage-labels.md` 右列；
3. 在那份副本里写下**为什么它与本默认不同** —— 下一个接手的人只读得到副本。

★ 本文件**有意不在副本一致性门里**（判据与理由见工作区根的
`Docs/baseline-copies.manifest.mjs`「共享的 agent 约定」段 —— ⛔ 这里**有意不写成相对链接**：
本文件会被复制进各项目 `docs/agents/`，那一层解不开这条路径）：
它是**各项目可以分化的默认值**，不是强制抄件。
⇒ 上面那张读数表描述的是 2026-09-09 那天的实况，**不是不变量**；⛔ 引用前现查。

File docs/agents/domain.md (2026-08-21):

---
type: convention
title: Agent skill domain documentation
description: Defines how engineering skills locate domain context and architectural decisions.
tags: [agents, domain-docs, adr]
status: stable
---

# Domain Docs

## Selected layout

This target uses the **single-context** domain-doc layout. Read a root `CONTEXT.md` and root `docs/adr/` when they exist.

How the engineering skills should consume this repo's domain documentation when exploring the codebase.

## Before exploring, read these

- **`CONTEXT.md`** at the repo root, or
- **`CONTEXT-MAP.md`** at the repo root if it exists: it points at one `CONTEXT.md` per context. Read each one relevant to the topic.
- **`docs/adr/`**: read ADRs that touch the area you're about to work in. In multi-context repos, also check `src/<context>/docs/adr/` for context-scoped decisions.

If any of these files don't exist, **proceed silently**. Don't flag their absence; don't suggest creating them upfront. The `/domain-modeling` skill (reached via `/grill-with-docs` and `/improve-codebase-architecture`) creates them lazily when terms or decisions actually get resolved.

## File structure

Single-context repo (most repos):

```
/
├── CONTEXT.md
├── docs/adr/
│   ├── 0001-event-sourced-orders.md
│   └── 0002-postgres-for-write-model.md
└── src/
```

Multi-context repo (presence of `CONTEXT-MAP.md` at the root):

```
/
├── CONTEXT-MAP.md
├── docs/adr/                          ← system-wide decisions
└── src/
    ├── ordering/
    │   ├── CONTEXT.md
    │   └── docs/adr/                  ← context-specific decisions
    └── billing/
        ├── CONTEXT.md
        └── docs/adr/
```

## Use the glossary's vocabulary

When your output names a domain concept (in an issue title, a refactor proposal, a hypothesis, a test name), use the term as defined in `CONTEXT.md`. Don't drift to synonyms the glossary explicitly avoids.

If the concept you need isn't in the glossary yet, that's a signal: either you're inventing language the project doesn't use (reconsider) or there's a real gap (note it for `/domain-modeling`).

## Flag ADR conflicts

If your output contradicts an existing ADR, surface it explicitly rather than silently overriding:

> _Contradicts ADR-0007 (event-sourced orders), but worth reopening because…_

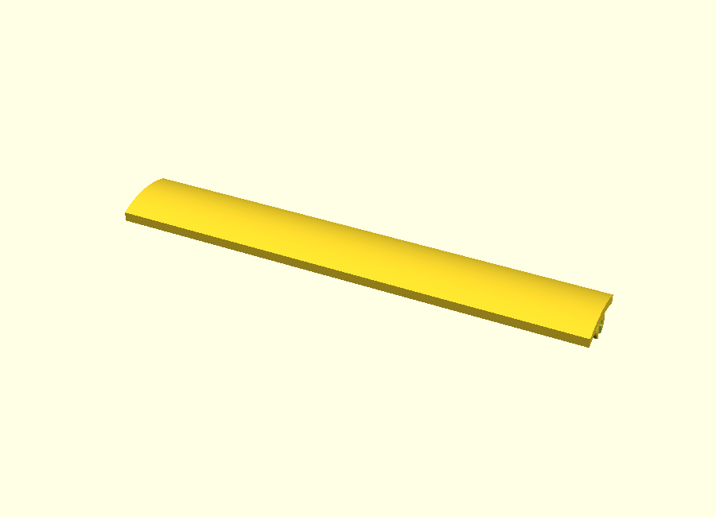
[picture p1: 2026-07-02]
cad/preview/blade.png

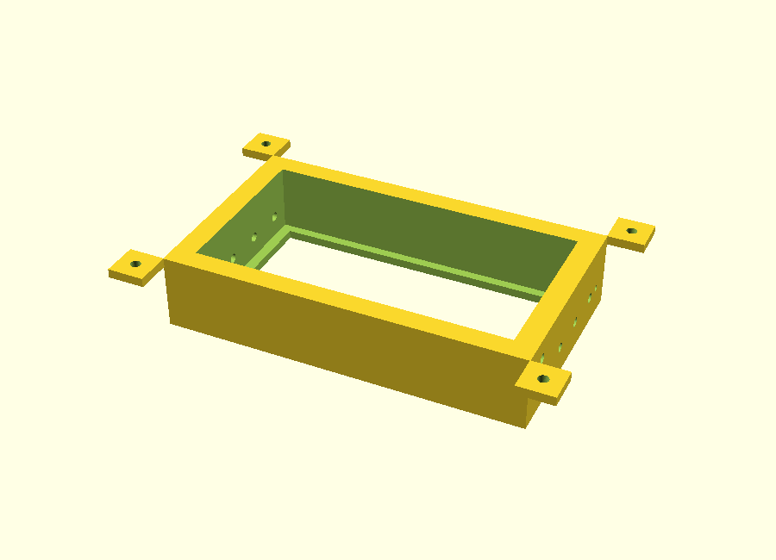
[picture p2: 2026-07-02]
cad/preview/frame.png

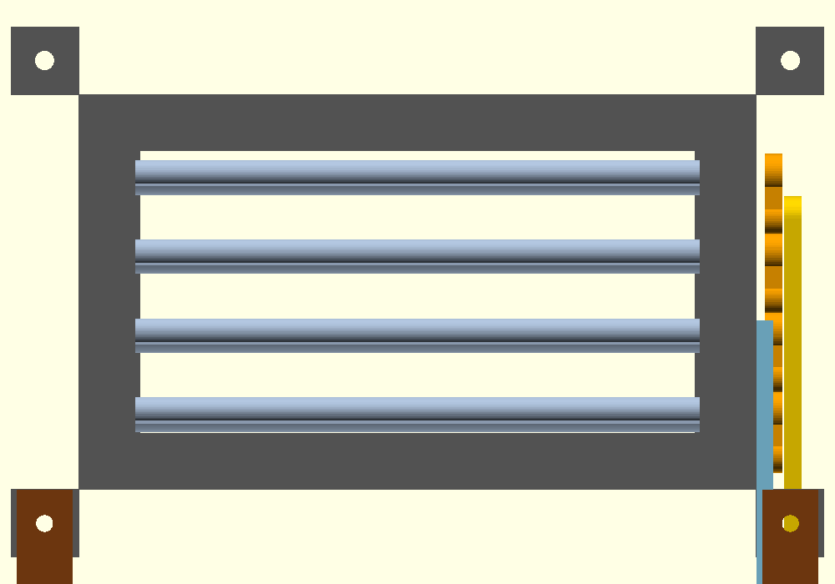
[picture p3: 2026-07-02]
cad/preview/front_90.png

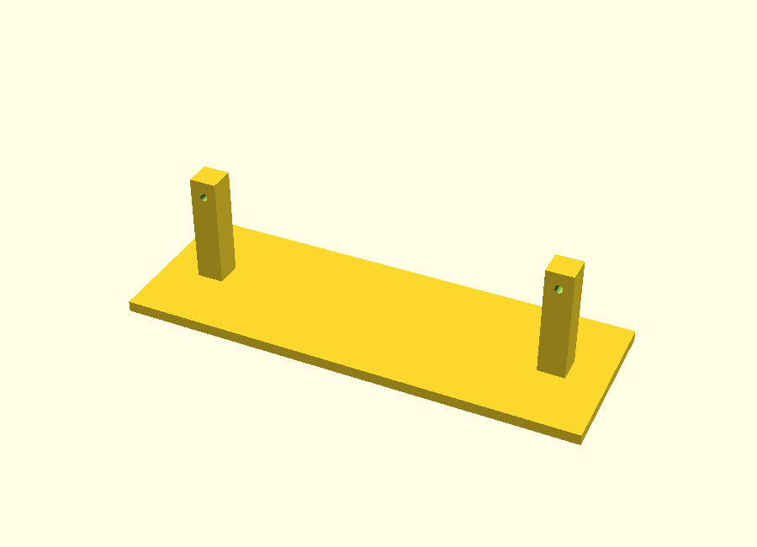
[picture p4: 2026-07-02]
cad/preview/stand.png

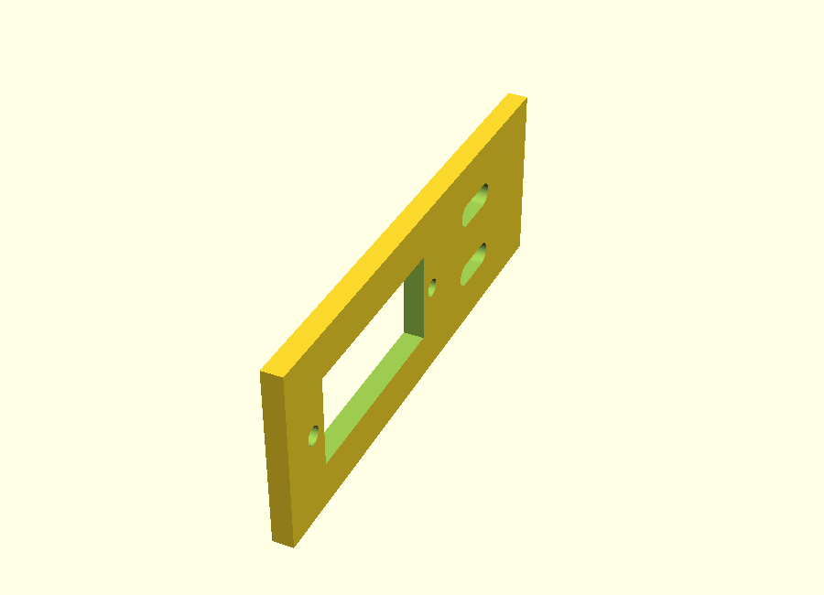
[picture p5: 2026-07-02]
cad/preview/servo_bracket.png

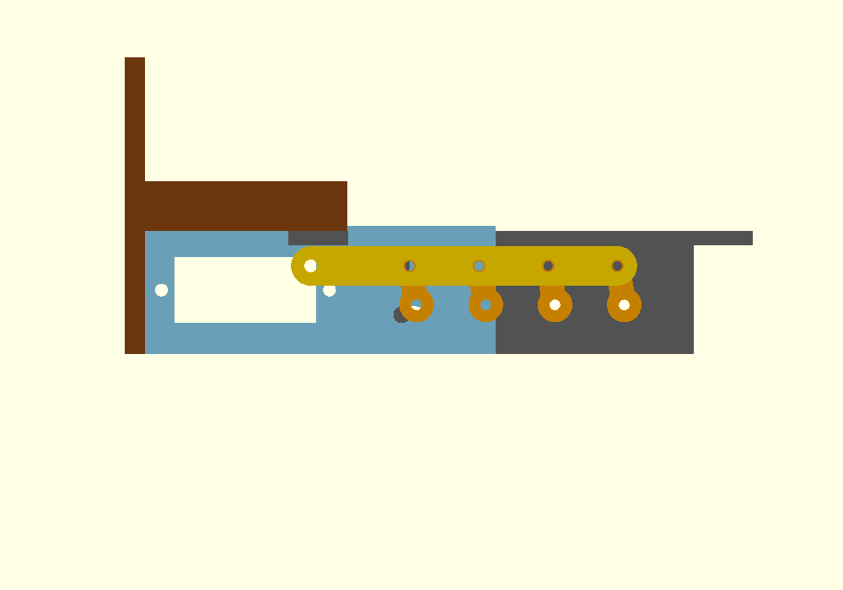
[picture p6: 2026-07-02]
cad/preview/side_10.png

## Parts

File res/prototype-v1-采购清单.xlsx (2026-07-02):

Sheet: 台架采购清单
序号 | 分类 | 品名 | 推荐型号 / 规格 | 数量 | 单位 | 参考单价(¥) | 小计(¥) | 淘宝搜索关键词 | 必要性 | 备注 / 免焊要点
1 | 电子核心 | ESP32 开发板 | ESP32-WROOM-32 DevKitC 38Pin(CP2102 串口) | 2 | 块 | 25.00 | 50.00 | ESP32 开发板 38Pin CP2102 | 必买 | 含 1 块备件。出厂已焊排针;★与扩展板同店配套买,确认 38P 排针间距匹配
2 | 电子核心 | ESP32 扩展板 | 38Pin GPIO 扩展板(螺丝端子引出) | 1 | 块 | 12.00 | 12.00 | ESP32 38Pin 扩展板 端子 | 必买 | ★免焊关键件:端子拧线代替焊接,比面包板抗振;台架/装车通用。ESP32 直插面包板会盖满两侧孔,主控一律走扩展板
3 | 电子核心 | 数字空速计(压差)套装 | MS4525DO 模块 + PT40 皮托管 + 40cm 软管 + GH4P 线 | 1 | 套 | 180.00 | 180.00 | MS4525 空速计 pixhawk 皮托管 | 必买 | ±1psi / 14 位 / 分辨率 0.84Pa;5V 供电、I2C 3.3V。行情约 ¥150-230;若有 2.54 排针版列表优先选(可省转接线)
4 | 电子核心 | GH 转杜邦转接线 | GH1.25 4P 单头 → 2.54 杜邦母 | 2 | 根 | 4.00 | 8.00 | GH1.25 转杜邦 4P | 必买 | ★空速计套装默认 GH 小座非杜邦——免焊约束下必须此线转接;若买到排针版空速计则闲置
5 | 电子核心 | 舵机 | EMAX ES3054(17g·数字·金属齿·双滚珠轴承·3.5kg·cm@6V·行程 145°) | 2 | 只 | 45.00 | 90.00 | EMAX ES3054 舵机 | 必买 | 含 1 只备件。已查证:数字+金属齿+双轴承;脉宽 700-2300µs,固件 us0/us90 装配后标定;JR 插头即 3P 杜邦
6 | 电子核心 | IMU 模块 | GY-521(MPU6050) | 2 | 块 | 6.00 | 12.00 | GY-521 MPU6050 已焊排针 | 必买 | 含 1 块备件。★发货选项必选「已焊排针」;AD0 接 3V3 → 地址 0x69(避开 DS3231 的 0x68)
7 | 电子核心 | 气压温度模块 | GY-BMP280-3.3 | 2 | 块 | 5.00 | 10.00 | BMP280 模块 已焊排针 | 必买 | 含 1 块备件。★已焊排针;SDO→GND(地址 0x76)、CSB→3V3(锁 I2C 模式)
8 | 电子核心 | RTC 时钟模块 | DS3231(ZS-042)+ LIR2032 充电纽扣电池 | 1 | 块 | 10.00 | 10.00 | DS3231 模块 LIR2032 | 必买 | ★必须选配 LIR2032 可充电版:若配 CR2032 需拆板上充电电阻 = 焊接活(不做)。已焊排针
9 | 电子核心 | microSD 模块 | 3.3V 直连 6P SPI 小板(勿买 5V 电平转换大板) | 2 | 块 | 3.00 | 6.00 | microSD 模块 SPI 3.3V | 必买 | 含 1 块备件。★已焊排针;3.3V 直连型与 ESP32 匹配
10 | 电子核心 | microSD 卡 | 32GB Class10(金士顿 / 闪迪正品) | 2 | 张 | 20.00 | 40.00 | microSD 32G class10 | 必买 | ★必须格式化为 FAT32:Windows 对 32G 默认 exFAT,SD 库不识别
11 | 电子核心 | GPS 模块 | GY-GPS6MV2(NEO-6M + 陶瓷天线) | 1 | 块 | 25.00 | 25.00 | NEO-6M GPS 模块 已焊排针 | 必买 | ★已焊排针;冷启动需露天数分钟。可选升级 NEO-M8N(约 ¥50)搜星更快
12 | 供电 | USB 充电宝 | 5V ≥2A,支持小电流模式(手环模式) | 1 | 个 | 50.00 | 50.00 | 充电宝 小电流模式 | 已有可跳过 | ★普通充电宝负载 <100mA 几分钟自动断电 → 日志中断(断电本身无害,弹簧回闭合)。已有的先实测会不会自动断
13 | 供电 | USB 取电转接板 | USB-A 公头 → 接线端子小板(免焊) | 2 | 个 | 3.00 | 6.00 | USB公头 转接线端子 | 必买 | 从充电宝取 5V 进主轨;端子拧线,整洁可靠
14 | 供电 | 电解电容 | 470µF / 16V 直插 | 5 | 只 | 0.60 | 3.00 | 470uF 16V 电解电容 | 必买 | 舵机供电就近并联防压降复位;插端子 / 面包板即可,免焊。注意极性(长脚为正)
15 | 供电 | USB 数据线 | micro-USB(确认支持数据传输) | 1 | 根 | 8.00 | 8.00 | microUSB 数据线 | 已有可跳过 | ★必须是数据线:纯充电线刷不了固件、进不了串口
16 | 供电 | USB 带开关延长线 | USB 公母延长线带开关 | 1 | 根 | 5.00 | 5.00 | USB 延长线 带开关 | 可选 | 台架总电门;做「断电弹簧回闭合」实测很方便
17 | 连接线材 | 杜邦线 | 公母 / 母母 / 公公 10+20cm 混装 120 根 | 1 | 盒 | 12.00 | 12.00 | 杜邦线 120根 混装 | 必买 | 免焊主力;分色多备
18 | 连接线材 | 面包板 | 830 孔 | 2 | 块 | 6.00 | 12.00 | 面包板 830孔 | 必买 | 传感器分区试接用(主控走扩展板)
19 | 连接线材 | 舵机延长线 | 30cm 公母 3P | 2 | 根 | 2.00 | 4.00 | 舵机延长线 30cm | 必买 | 舵机到扩展板的距离余量
20 | 连接线材 | 免焊快速接线端子 | WAGO 型 2 位 / 3 位混装 | 10 | 个 | 1.20 | 12.00 | 快速接线端子 按压式 | 必买 | 5V / GND 电源分线(ESP32 + 舵机 + GPS 共轨)免焊神器
21 | 连接线材 | 扎带 + 魔术贴 | 尼龙扎带 3×100mm 100 根 + 魔术贴扎带卷 | 1 | 套 | 8.00 | 8.00 | 尼龙扎带 魔术贴扎带 | 必买 | 走线固定
22 | 连接线材 | 电工胶带 | PVC 绝缘胶带 | 1 | 卷 | 3.00 | 3.00 | 电工胶带 | 必买
23 | 连接线材 | 硅胶软管 | 内径 3mm 硅胶管 2m | 1 | 根 | 5.00 | 5.00 | 硅胶管 3mm | 可选 | 皮托软管延长备用(套装自带 40cm)
24 | 机构五金 | 球头拉杆组 | M2 球头 ×10 + M2 螺纹杆 30/40mm 各 5 根 | 1 | 套 | 15.00 | 15.00 | M2 球头拉杆 舵机 | 必买 | 叶片曲柄联动拉杆;比弯钢丝省事精准,纯螺纹装配免工具活
25 | 机构五金 | 舵机快速调节夹 | 易拉夹(拉杆锁紧器)Φ2 | 10 | 个 | 0.80 | 8.00 | 舵机 易拉夹 快速调节器 | 必买 | 拉杆长度免焊免弯微调
26 | 机构五金 | 不锈钢轴 | Φ2mm 圆棒 300mm | 2 | 根 | 3.00 | 6.00 | 不锈钢棒 2mm | 必买 | 叶片转轴,按叶宽剪断
27 | 机构五金 | 黄铜轴套管 | 内 2 / 外 3mm 黄铜管 300mm | 2 | 根 | 4.00 | 8.00 | 黄铜管 2x3mm | 必买 | 打印件轴孔内衬,转动顺滑不磨料
28 | 机构五金 | 扭簧试配包 | 线径 0.3-0.5mm 小扭簧多规格 | 1 | 包 | 12.00 | 12.00 | 小扭簧 多规格 扭转弹簧 | 必买 | 断电回位;多规格试配,目标回位力矩 ≤0.5kg·cm(舵机 3.5kg·cm 裕量 7 倍)
29 | 机构五金 | 螺丝套装 | M2 / M2.5 / M3 盒装(含螺母垫片) | 1 | 盒 | 20.00 | 20.00 | M2 M3 螺丝盒装套装 | 必买 | 模块与机构紧固
30 | 机构五金 | 尼龙柱套装 | M3 尼龙隔离柱 / 螺柱盒装 | 1 | 盒 | 10.00 | 10.00 | M3 尼龙柱 套装 | 必买 | 模块架高装在打印底板上,防短路
31 | 机构五金 | 3D 打印耗材 | PETG 1kg(装车件);台架件用 PLA 快速迭代 | 1 | 卷 | 55.00 | 55.00 | PETG 耗材 1kg | 可选 | ★2026-07-02 路线变更:打印全走农场代打 PA12/PA12-CF(见 cad/dist),自有耗材仅备用;原 PLA→PETG 路线作废
32 | 工具辅材 | 热熔胶枪 | 小号胶枪 + 胶棒 20 根 | 1 | 套 | 25.00 | 25.00 | 热熔胶枪 套装 | 必买 | 模块固定 / 线缆应力释放(点名件)
33 | 工具辅材 | 数显游标卡尺 | 150mm | 1 | 把 | 25.00 | 25.00 | 数显游标卡尺 150 | 已有可跳过 | 机构 CAD 量尺寸必备
34 | 工具辅材 | 万用表 | 有电压 / 通断挡即可 | 1 | 台 | 40.00 | 40.00 | 万用表 | 已有可跳过 | ★上电前查 5V/GND 短路,是免焊流程的安全底线
35 | 工具辅材 | 精密螺丝刀套装 | 十字 / 一字小号 | 1 | 套 | 15.00 | 15.00 | 精密螺丝刀套装 | 已有可跳过
36 | 工具辅材 | 3M VHB 双面胶 | 宽 10-20mm | 1 | 卷 | 8.00 | 8.00 | 3M VHB 双面胶 | 必买 | 充电宝 / 模块临时固定
37 | 工具辅材 | USB 读卡器 | microSD → USB | 1 | 个 | 8.00 | 8.00 | microSD 读卡器 typec | 已有可跳过 | 取 SD 日志
38 | 工具辅材 | 环氧 AB 胶 | 5 分钟固化型(哥俩好/爱牢达) | 1 | 支 | 10.00 | 10.00 | 环氧AB胶 5分钟 | 必买 | ★PA12 尼龙粘不住 502/CA:钢轴入叶槽、曲柄固轴端一律用环氧,粘接面砂纸打毛
 |  |  | 合计(全部) |  |  |  | 836.00
 |  |  | 其中 · 必买合计 |  |  |  | 625.00
 |  |  | 其中 · 已有可跳过(家里都有则可省) |  |  |  | 146.00
 |  |  | 其中 · 可选 |  |  |  | 65.00
 |  |  | 注:参考单价为 2026-07 淘宝行情估算,以实际商品页为准;合计作量级参考。

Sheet: 阶段二·装车追加(暂不买)
序号 | 分类 | 品名 | 推荐型号 / 规格 | 数量 | 参考单价(¥) | 小计(¥) | 备注 / 触发条件
1 | 供电 | 降压模块 | 12V→5V / 3A,带螺丝端子已焊好 | 1 | 10.00 | 10.00 | 取车电(OQ-3 阶段二);端子拧线免焊
2 | 供电 | 保险丝座 + 保险丝 | 车用插片保险丝座带线 + 2A / 5A 保险丝 | 2 | 4.00 | 8.00 | 取车电必加(OQ-10 安全);带线免焊对接 WAGO
3 | 供电 | 电源开关 | 车用防水船型开关(带线) | 1 | 6.00 | 6.00 | 整车电门
4 | 外壳 | 防水接线盒 | ABS IP65 小号(约 100×68×50) | 1 | 15.00 | 15.00 | 电子仓;走线孔用胶枪封
5 | 连接 | XH2.54 成品线 | 双头 XH 2/3/4P 成品线各若干 | 1 | 12.00 | 12.00 | 配定制底板用;★买成品,免压线钳
6 | PCB | 模块底板定制 | 嘉立创:PCB 5 片(约 ¥30)+ SMT / 插件焊接服务(排母·XH 座·端子·电容·保险丝座全由板厂焊) | 1 | 120.00 | 120.00 | ★台架六步验证通过后再设计;引脚映射按 docs/img/wiring-v1.svg 固化;详见「说明与PCB方案」页
7 | 机构 | PETG 装车件重打 | 台架 PLA 件定型后换 PETG 重打 | 1 | 0.00 | 0.00 | 耗材已列台架清单
 |  |  | 阶段二合计 |  |  | 171.00

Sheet: 说明与PCB方案
项目 | 内容
审核依据 | 2026-07-02 · 基于 docs/prototype-v1.md 初版 BOM 全面复审;新增约束:owner 零烙铁——不做任何锡焊,一切需焊接的工序走网上打板 + 贴片 / 插件焊接(嘉立创类)。
免焊三原则 | ① 模块一律选「已焊排针」发货选项(GY 系模块默认散针须自焊——不接受);② 连接一律走杜邦线 / 螺丝端子 / WAGO 免焊端子;③ 确实需要焊的,全部集中到定制底板由板厂焊完,到手即插。
与初版 BOM 的变更 1 | 新增「ESP32 38Pin 扩展板(端子引出)」:免焊关键件,同时解决 ESP32 直插面包板盖孔的问题,且抗振可直接沿用到装车。
与初版 BOM 的变更 2 | 新增「GH1.25 4P 转杜邦母转接线」:经查证,MS4525DO 空速计套装出厂标配 JST-GH 小座线(Pixhawk 规格),不是杜邦——不转接就得动烙铁。
与初版 BOM 的变更 3 | DS3231 指定 LIR2032 充电版:通配 CR2032 需拆板上充电电阻(焊接活),不做。
与初版 BOM 的变更 4 | 机构联动由「弯钢丝拉杆」改为「M2 球头拉杆 + 易拉夹」:纯螺纹装配 + 免焊微调,单人可造性更好。
与初版 BOM 的变更 5 | 备件策略:低价易损件(ESP32 / 舵机 / IMU / BMP280 / SD 模块 / SD 卡)一律 ×2;贵件(空速计 / GPS / RTC)×1。
与初版 BOM 的变更 6 | 补齐辅材:热熔胶枪(点名)、WAGO 免焊端子、USB 取电转接板、扎带 / 魔术贴 / 双面胶、轴材(2mm 不锈钢轴 + 黄铜轴套)、尼龙柱、读卡器等。
与初版 BOM 的变更 7 | 舵机型号已查证坐实:EMAX ES3054 = 17g · 数字 · 金属齿 · 双滚珠轴承 · 3.0-3.5kg·cm · 行程 145°(700-2300µs),符合拍板的「17-25g 迷你金属数字舵」。
与初版 BOM 的变更 8 | SD 卡明确 32GB Class10 并标注 FAT32 格式化要求(Windows 默认 exFAT,SD 库不识别)。
PCB 定制要不要? | 【结论】台架阶段:不需要。模块全部已焊排针 + 扩展板端子 + 杜邦 / WAGO,可 100% 零烙铁跑通全链(prototype-v1.md §6 的六步验证)。
PCB 定制方案(装车阶段·推荐) | 定制一块「模块底板(carrier board)」:板上只放排母(模块像内存条一样插上)、XH 座、螺丝端子、470µF 电容位、保险丝座——全部由嘉立创贴片 + 插件焊接服务焊好,到手零烙铁。作用:消灭杜邦线(抗振可靠)、走线固化、装进防水盒。费用约 ¥90-150(PCB 5 片 ~¥30 + 焊接服务与元件)。
PCB 为什么不做芯片级全集成 | 把 ESP32 / MS4525 / MPU6050 等芯片直接画上板虽最紧凑,但:① MS4525DO 芯片单买难且贵;② 一次成板,画错即报废重投,迭代风险高;③ 违背「第一周可观察 / 单人可造」铁律。模块底板方案模块可插拔、坏件即换,迭代零风险——v1 的正确档位。
PCB 时点 | 台架六步验证全部跑通、引脚 / 参数不再变动后,再按 docs/img/wiring-v1.svg 的映射画底板(那时接线图升级为底板原理图)。
价格声明 | 参考单价为 2026-07 淘宝行情估算,以实际商品页为准;合计作量级参考。

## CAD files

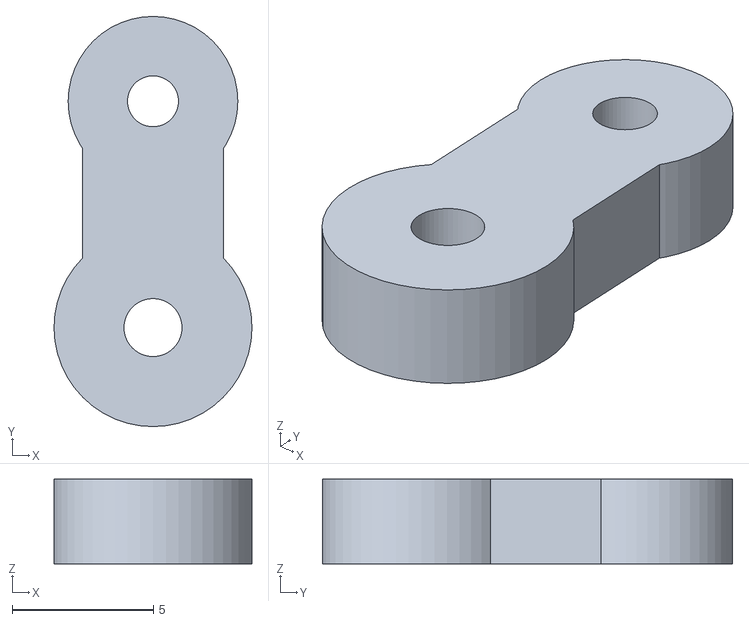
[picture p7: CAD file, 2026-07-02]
cad/dist/03_crank_x4.stl
7.00 x 14.5 x 3.00

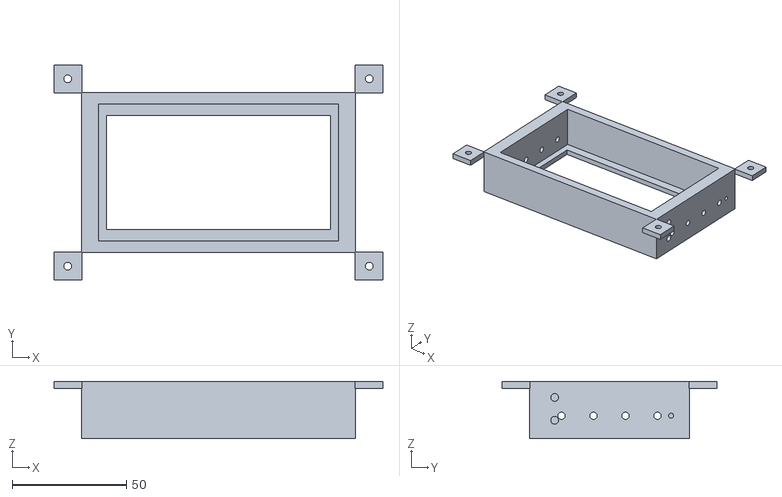
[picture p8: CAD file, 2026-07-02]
cad/stl/frame.stl
144.0 x 94.0 x 25.0

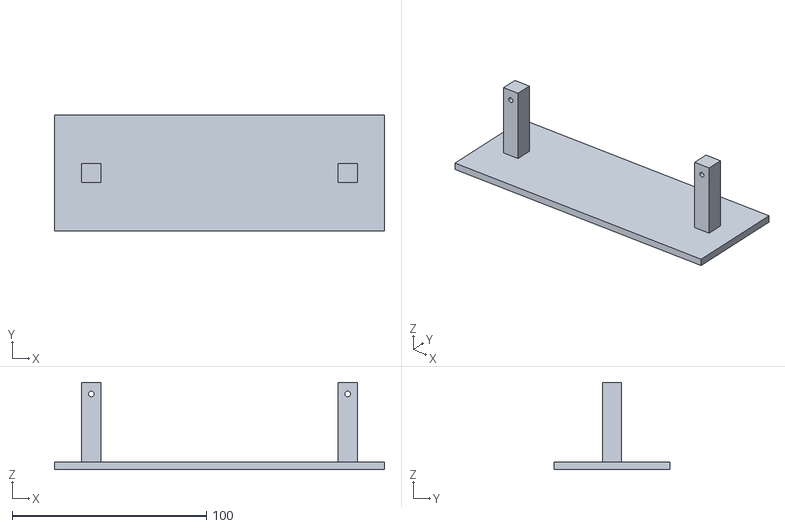
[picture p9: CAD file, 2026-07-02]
cad/dist/06_stand_x1.stl
170.0 x 60.0 x 45.0

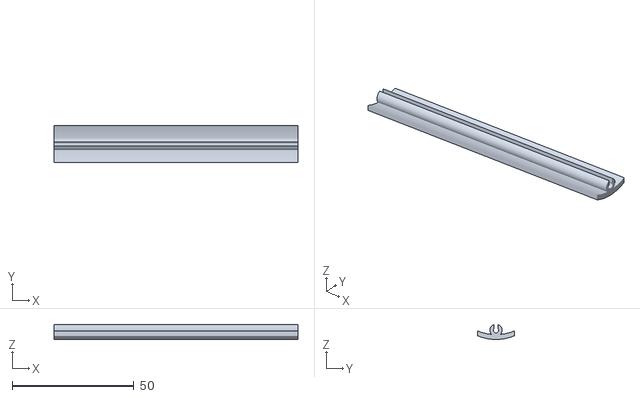
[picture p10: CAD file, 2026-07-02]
cad/dist/02_blade_x4.stl
100.0 x 15.0 x 6.13

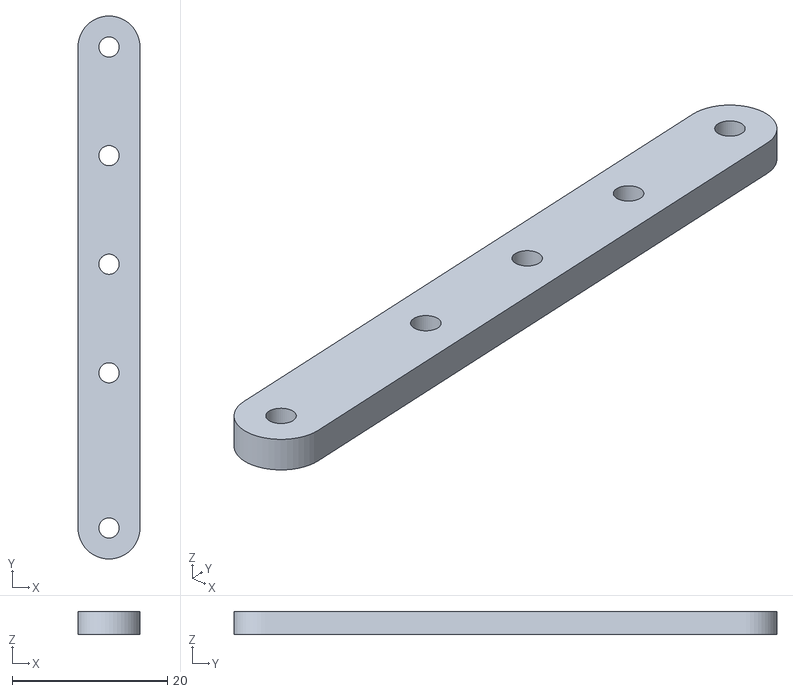
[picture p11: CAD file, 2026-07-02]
cad/stl/linkbar.stl
8.00 x 70.0 x 3.00

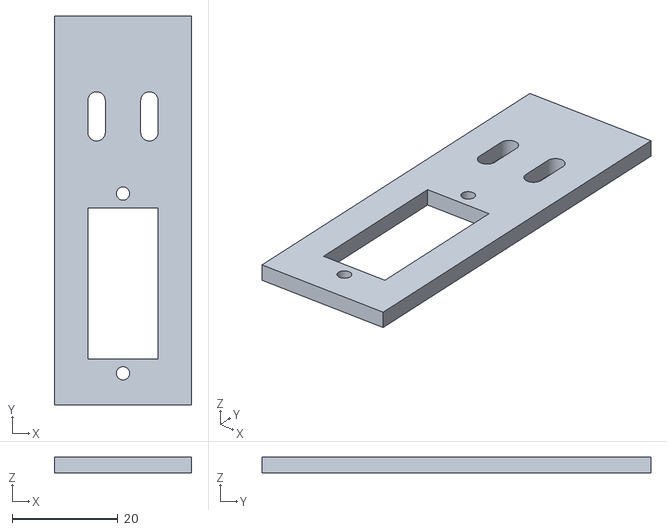
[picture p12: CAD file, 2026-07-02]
cad/dist/05_servo_bracket_x1.stl
26.0 x 73.6 x 3.00

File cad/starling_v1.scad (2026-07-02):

// ============================================================================
// Starling 原型一号 · 机构参数化模型 v0.1(台架版)
// OpenSCAD 源文件 —— 唯一 CAD 真相;STL 由本文件导出,勿手编 STL。
//
// 用法:
//   GUI:打开本文件,改底部 PART 变量预览 / F6 渲染 / 导出 STL;
//   CLI:openscad -o stl/frame.stl -D "PART=\"frame\"" starling_v1.scad
//   装配预览:PART="assembly",OPEN_DEG=CLOSED_DEG(闭合)~90(全开)
//
// 打印件清单:frame ×1 · blade ×4 · crank ×4 · linkbar ×1
//            servo_bracket ×1 · stand ×1
// 外购件:Ø2 不锈钢轴(切 4 段×125)· 黄铜套内2外3(切 8 段×6)
//        M2 球头拉杆一组(舵机臂→拉杆下孔)· M2/M3 螺丝 · 扭簧 · EMAX ES3054
//
// ★ 到货必须卡尺复测再打印的参数:SV_*(舵机三项)、BUSH_OD、SHAFT_D
// ★ 机构行程:闭合 = CLOSED_DEG(10°,微倾使相邻叶鳞片式搭接不干涉),
//   全开 = 90°(水平);固件把 0-100% 开度映射到 10°-90°。
// ============================================================================

// ---------------- 全局参数(单位 mm) ----------------
FRAME_W  = 120;   // 框外宽(X)
FRAME_H  = 70;    // 框外高(Y)
FRAME_D  = 25;    // 框深/喉道(Z;前脸 z=0,喉道向 +Z)
LIP_T    = 3;     // 前脸包边板厚
OPEN_W   = 105;   // 内腔宽(叶片区)
OPEN_H   = 60;   // 内腔高(叶尖扫掠 ±28.9 → 留 1.1 间隙)
LIP_W    = 98;    // 前脸窗宽(包住叶端 3.5mm×2)
LIP_H    = 50;    // 前脸窗高(包住上下叶行程 3mm×2)
AXIS_Z   = 10;    // 叶轴线距前脸深度

N_BLADE  = 4;
PITCH    = 14;    // 叶片轴距(弦 15 → 闭合搭接 1mm)
BLADE_L  = 100;   // 叶长
CHORD    = 15;    // 叶弦
BLADE_T  = 2.0;   // 叶厚
CAMBER   = 1.5;   // 拱高(前凸)
CLOSED_DEG = 10;  // 闭合角(见文件头注释)

SHAFT_D  = 2.0;   // 钢轴径 ★复测
BUSH_OD  = 3.0;   // 黄铜套外径 ★复测
HOLE_COMP= 0.2;   // FDM 孔收缩补偿:所有孔径 = 目标实际尺寸 + 此值

CRANK_R  = 8;     // 曲柄半径(舵盘也取 8mm 孔 → 1:1)
CRANK_T  = 3;
CRANK_HUB= 7;     // 曲柄毂径
CRANK_GAP= 1.5;   // 曲柄内侧面与框外壁间隙

LINK_W   = 8;     // 拉杆截面宽
LINK_T   = 3;     // 拉杆厚
LINK_EXT = 20;    // 拉杆自最下曲柄销孔向下延伸至球头孔的距离

EAR      = 12;    // 安装耳边长
$fn = 48;

// ---- 舵机 EMAX ES3054(★全部到货复测) ----
SV_BODY_L = 28.6;    // 体长(留 0.2 装配余量)
SV_BODY_W = 13.2;    // 体宽
SV_HOLE_SPAN = 34.0; // 两安装孔中心距 ★最关键
SV_SCREW  = 2.4;     // 安装孔过孔径(配自带自攻钉)
SV_AXIS_OFF = 9.7;   // 输出轴中心距体上端的偏移 ★复测
SV_DROP  = 30;       // 舵机轴位于最下叶轴之下的距离(球头短杆可调,允差大)

// ---------------- 派生量 ----------------
function hd(d) = d + HOLE_COMP;              // 孔径补偿
COL_W    = (FRAME_W-OPEN_W)/2;               // 侧柱厚 7.5
BLADE_Y  = [ for (i=[0:N_BLADE-1]) (i-(N_BLADE-1)/2)*PITCH ]; // -21,-7,7,21
Y_BOT    = BLADE_Y[0];
Y_TOP    = BLADE_Y[N_BLADE-1];
CRANK_X  = FRAME_W/2 + CRANK_GAP;            // 曲柄内侧面 x
SPINE_Z  = -BLADE_T - 0.3;                   // 叶背脊/轴心相对叶弦面的 z
SV_AXIS_Y = Y_BOT - SV_DROP;                 // 舵机输出轴 y(-51)
SV_BODY_C = SV_AXIS_Y + SV_AXIS_OFF - SV_BODY_L/2; // 舵机体中心 y

echo("== Starling v0.1 派生量 ==");
echo(COL_W=COL_W, BLADE_Y=BLADE_Y, CRANK_X=CRANK_X, SV_AXIS_Y=SV_AXIS_Y);

// ============================================================================
// 零件 1:固定框 frame
// 前脸 z=0;两侧实心柱(厚 COL_W)带轴孔;后侧通透;四角安装耳(后缘)
// ============================================================================
module frame() {
  difference() {
    union() {
      translate([-FRAME_W/2, -FRAME_H/2, 0]) cube([FRAME_W, FRAME_H, FRAME_D]);
      for (sx=[-1,1], sy=[-1,1])   // 安装耳(后缘平面;嵌入本体 0.2 保证融合)
        translate([sx>0 ? FRAME_W/2-0.2 : -FRAME_W/2-EAR,
                   sy>0 ? FRAME_H/2-0.2 : -FRAME_H/2-EAR,
                   FRAME_D-3])
          cube([EAR+0.2, EAR+0.2, 3]);
    }
    // 前脸窗(包边圈)
    translate([-LIP_W/2, -LIP_H/2, -0.5]) cube([LIP_W, LIP_H, LIP_T+0.5]);
    // 主腔(叶片区,后侧通透;向前重叠 0.2 避免与前脸窗切割面共面)
    translate([-OPEN_W/2, -OPEN_H/2, LIP_T-0.2]) cube([OPEN_W, OPEN_H, FRAME_D]);
    // 轴套孔:Ø3(黄铜套压入),两侧柱贯通
    for (y=BLADE_Y)
      translate([-FRAME_W/2-1, y, AXIS_Z]) rotate([0,90,0])
        cylinder(d=hd(BUSH_OD), h=FRAME_W+2);
    // 扭簧锚孔(右柱,顶叶轴上方 6mm,Ø2 贯通)
    translate([FRAME_W/2-COL_W-1, Y_TOP+6, AXIS_Z]) rotate([0,90,0])
      cylinder(d=hd(2), h=COL_W+2);
    // 舵机支架安装孔:右柱下部 2×M3 贯通
    for (z=[8,18])
      translate([FRAME_W/2-COL_W-1, -FRAME_H/2+11, z]) rotate([0,90,0])
        cylinder(d=hd(3.2), h=COL_W+2);
    // 安装耳 M3 孔(轴向 Z)
    for (sx=[-1,1], sy=[-1,1])
      translate([sx*(FRAME_W/2+EAR/2), sy*(FRAME_H/2+EAR/2), FRAME_D-4])
        cylinder(d=hd(3.2), h=5);
  }
}

// ============================================================================
// 零件 2:叶片 blade
// 局部系:挤出沿 X;截面 (Y,Z):弦沿 Y(闭合姿态)、前凸 +Z;
// 钢轴槽心在 (y=0, z=SPINE_Z);装配时该点对齐框轴孔,旋转绕 X。
// ============================================================================
module blade_profile() {   // 2D:(弦向, 拱向)
  R  = (CHORD*CHORD/4 + CAMBER*CAMBER)/(2*CAMBER);
  A  = asin((CHORD/2)/R);
  zc = CAMBER - R;
  pts_out = [ for (t=[-A:A/16:A])  [R*sin(t), zc + R*cos(t)] ];
  pts_in  = [ for (t=[A:-A/16:-A]) [R*sin(t), zc + R*cos(t) - BLADE_T] ];
  polygon(concat(pts_out, pts_in));
}
module blade() {
  difference() {
    union() {
      // 弧板:2D(x=弦,y=拱) → 旋转使 弦→Y、拱→+Z、挤出→X
      translate([-BLADE_L/2,0,0]) rotate([0,90,0]) rotate([0,0,90])
        linear_extrude(BLADE_L) blade_profile();
      // 背脊(容轴)
      translate([-BLADE_L/2, 0, SPINE_Z]) rotate([0,90,0]) cylinder(d=5, h=BLADE_L);
    }
    // 轴道 Ø2.1 + 朝后 1.8 开口槽(钢轴卡入 + CA 胶)
    translate([-BLADE_L/2-1, 0, SPINE_Z]) rotate([0,90,0])
      cylinder(d=hd(SHAFT_D+0.1), h=BLADE_L+2);
    translate([-BLADE_L/2-1, -0.9, SPINE_Z-5]) cube([BLADE_L+2, 1.8, 5]);
  }
}

// ============================================================================
// 零件 3:曲柄 crank(毂过盈+CA 压钢轴端;销孔 M2 自攻)
// 局部系:毂心=原点,臂沿 +Y,厚沿 +Z
// ============================================================================
module crank() {
  difference() {
    union() {
      cylinder(d=CRANK_HUB, h=CRANK_T);
      translate([-2.5, 0, 0]) cube([5, CRANK_R, CRANK_T]);
      translate([0, CRANK_R, 0]) cylinder(d=6, h=CRANK_T);
    }
    translate([0,0,-1]) cylinder(d=hd(SHAFT_D-0.05), h=CRANK_T+2); // 轴孔(过盈)
    translate([0, CRANK_R, -1]) cylinder(d=hd(1.7), h=CRANK_T+2);  // M2 自攻底孔
  }
}

// ============================================================================
// 零件 4:拉杆 linkbar(平放建模:长沿 Y,厚沿 Z)
// 孔位:y=0..(N-1)*PITCH 曲柄销 ×4;y=-LINK_EXT 球头/舵机侧孔
// ============================================================================
module linkbar() {
  L_TOP = (N_BLADE-1)*PITCH;
  difference() {
    hull() {
      translate([0, -LINK_EXT, 0]) cylinder(d=LINK_W, h=LINK_T);
      translate([0,  L_TOP,    0]) cylinder(d=LINK_W, h=LINK_T);
    }
    for (i=[0:N_BLADE-1])
      translate([0, i*PITCH, -1]) cylinder(d=hd(2.4), h=LINK_T+2); // M2 过孔
    translate([0, -LINK_EXT, -1]) cylinder(d=hd(2.4), h=LINK_T+2);
  }
}

// ============================================================================
// 零件 5:舵机支架 servo_bracket
// 局部系=装配系:贴壁面 x=0(装配时平移 FRAME_W/2),板厚 +X,宽沿 Z(0..26)
// 上段贴框右柱(2×M3 竖槽);下段开舵机窗(体竖装,轴朝 +X,轴心 y=SV_AXIS_Y)
// ============================================================================
module servo_bracket() {
  PT = 3; W = 26;
  TOP_Y  = -FRAME_H/2 + 30;              // 上段顶
  BOT_Y  = SV_BODY_C - SV_HOLE_SPAN/2 - 6; // 下段底(孔外留 6)
  difference() {
    translate([0, BOT_Y, 0]) cube([PT, TOP_Y-BOT_Y, W]);
    // 2×M3 竖长槽(对框柱孔 y=-24, z=8/18;允 ±3 调)
    for (z=[8,18]) hull() for (dy=[-3,3])
      translate([-1, -FRAME_H/2+11+dy, z]) rotate([0,90,0]) cylinder(d=hd(3.2), h=PT+2);
    // 舵机体窗口(轴心 y=SV_AXIS_Y → 体窗按 SV_AXIS_OFF 反推)
    translate([-1, SV_BODY_C - SV_BODY_L/2, W/2 - SV_BODY_W/2])
      cube([PT+2, SV_BODY_L, SV_BODY_W]);
    // 舵机安装孔 ×2(跨距中心 = 体中心)
    for (sy=[-1,1])
      translate([-1, SV_BODY_C + sy*SV_HOLE_SPAN/2, W/2]) rotate([0,90,0])
        cylinder(d=hd(SV_SCREW), h=PT+2);
  }
}

// ============================================================================
// 零件 6:台架座 stand(平放打印:基板在 XY,立柱 +Z)
// 装配姿态:rotate([-90,0,0]) 后立柱朝上、柱顶孔沿世界 Z,与框下两耳自攻对接
// ============================================================================
POST_H = 45; POST = 10;
module stand() {
  BASE_L = 170; BASE_W = 60; BASE_T = 4;
  difference() {
    union() {
      translate([-BASE_L/2, -BASE_W/2, 0]) cube([BASE_L, BASE_W, BASE_T]);
      for (sx=[-1,1])
        translate([sx*(FRAME_W/2+EAR/2)-POST/2, -POST/2, 0])
          cube([POST, POST, POST_H]);
    }
    for (sx=[-1,1])   // 柱顶 M3 自攻孔(沿局部 Y 贯通柱)
      translate([sx*(FRAME_W/2+EAR/2), POST/2+1, POST_H-6]) rotate([90,0,0])
        cylinder(d=hd(2.8), h=POST+2);
  }
}
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

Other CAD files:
cad/stl/stand.stl
cad/stl/crank.stl
cad/dist/01_frame_x1.stl
cad/stl/servo_bracket.stl
cad/dist/04_linkbar_x1.stl
cad/stl/blade.stl

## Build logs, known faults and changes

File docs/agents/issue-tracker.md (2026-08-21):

---
type: convention
title: Agent skill issue tracker
description: Defines where engineering skills read and write issues for this repository.
tags: [agents, issue-tracker]
status: stable
---

# Issue tracker: GitHub

Issues and specs for this repo live as GitHub issues. Use the `gh` CLI for all operations.

## Conventions

- **Create an issue**: `gh issue create --title "..." --body "..."`. Use a heredoc for multi-line bodies.
- **Read an issue**: `gh issue view <number> --comments`, filtering comments by `jq` and also fetching labels.
- **List issues**: `gh issue list --state open --json number,title,body,labels,comments --jq '[.[] | {number, title, body, labels: [.labels[].name], comments: [.comments[].body]}]'` with appropriate `--label` and `--state` filters.
- **Comment on an issue**: `gh issue comment <number> --body "..."`
- **Apply / remove labels**: `gh issue edit <number> --add-label "..."` / `--remove-label "..."`
- **Close**: `gh issue close <number> --comment "..."`

Infer the repo from `git remote -v`; `gh` does this automatically when run inside a clone.

## Pull requests as a triage surface

**PRs as a request surface: no.** _(Set to `yes` if this repo treats external PRs as feature requests; `/triage` reads this flag.)_

When set to `yes`, PRs run through the same labels and states as issues, using the `gh pr` equivalents:

- **Read a PR**: `gh pr view <number> --comments` and `gh pr diff <number>` for the diff.
- **List external PRs for triage**: `gh pr list --state open --json number,title,body,labels,author,authorAssociation,comments` then keep only `authorAssociation` of `CONTRIBUTOR`, `FIRST_TIME_CONTRIBUTOR`, or `NONE` (drop `OWNER`/`MEMBER`/`COLLABORATOR`).
- **Comment / label / close**: `gh pr comment`, `gh pr edit --add-label`/`--remove-label`, `gh pr close`.

GitHub shares one number space across issues and PRs, so a bare `#42` may be either: resolve with `gh pr view 42` and fall back to `gh issue view 42`.

## When a skill says "publish to the issue tracker"

Create a GitHub issue.

## When a skill says "fetch the relevant ticket"

Run `gh issue view <number> --comments`.

## Wayfinding operations

Used by `/wayfinder`. The **map** is a single issue with **child** issues as tickets.

- **Map**: a single issue labelled `wayfinder:map`, holding the Notes / Decisions-so-far / Fog body. `gh issue create --label wayfinder:map`.
- **Child ticket**: an issue linked to the map as a GitHub sub-issue (`gh api` on the sub-issues endpoint). Where sub-issues aren't enabled, add the child to a task list in the map body and put `Part of #<map>` at the top of the child body. Labels: `wayfinder:<type>` (`research`/`prototype`/`grilling`/`task`). Once claimed, the ticket is assigned to the driving dev.
- **Blocking**: GitHub's **native issue dependencies**, the canonical, UI-visible representation. Add an edge with `gh api --method POST repos/<owner>/<repo>/issues/<child>/dependencies/blocked_by -F issue_id=<blocker-db-id>`, where `<blocker-db-id>` is the blocker's numeric **database id** (`gh api repos/<owner>/<repo>/issues/<n> --jq .id`, _not_ the `#number` or `node_id`). GitHub reports `issue_dependencies_summary.blocked_by` (open blockers only, the live gate). Where dependencies aren't available, fall back to a `Blocked by: #<n>, #<n>` line at the top of the child body. A ticket is unblocked when every blocker is closed.
- **Frontier query**: list the map's open children (`gh issue list --state open`, scoped to the map's sub-issues / task list), drop any with an open blocker (`issue_dependencies_summary.blocked_by > 0`, or an open issue in the `Blocked by` line) or an assignee; first in map order wins.
- **Claim**: `gh issue edit <n> --add-assignee @me`, the session's first write.
- **Resolve**: `gh issue comment <n> --body "<answer>"`, then `gh issue close <n>`, then append a context pointer (gist + link) to the map's Decisions-so-far.

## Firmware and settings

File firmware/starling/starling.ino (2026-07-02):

// ============================================================================
// Starling 原型一号 · 固件骨架(2026-07-02)
// 目标板:ESP32 DevKit(WROOM-32) · Arduino 框架
//
// 链路:皮托管 → MS4525DO(I2C) → 阈值-斜坡曲线(滞回+限斜率+硬限位) → 舵机(百叶)
// 旁路:MPU6050 / BMP280 / DS3231 / GPS → microSD 10Hz CSV(纯被动记录,不进控制闭环)
// 配置:USB 串口 + 蓝牙 SPP 共用同一命令台(仅配置+取数,守 charter §3)
//
// ★ 状态:骨架代码——结构与控制律完整,尚未上板编译验证;
//   BMP280 补偿公式与 GPS NMEA 解析留 TODO(建议接 Adafruit_BMP280 / TinyGPSPlus 库)。
// ★ 边界(charter §3,勿改):无 OTA;蓝牙/串口不做任何实时开度控制;
//   test 命令仅在 IAS < 5 km/h(台架静止)时接受。
// ============================================================================

#include <Wire.h>
#include <SPI.h>
#include <SD.h>
#include <Preferences.h>
#include <BluetoothSerial.h>

// ---------------------------- 引脚与地址 ----------------------------
constexpr int PIN_I2C_SDA = 21;
constexpr int PIN_I2C_SCL = 22;
constexpr int PIN_SD_CS   = 5;    // VSPI:SCK=18 MISO=19 MOSI=23
constexpr int PIN_SERVO   = 13;   // LEDC 50Hz
constexpr int PIN_GPS_RX  = 16;   // UART2 ← GPS TX
constexpr int PIN_GPS_TX  = 17;   // UART2 → GPS RX

constexpr uint8_t ADDR_MS4525  = 0x28;
constexpr uint8_t ADDR_MPU6050 = 0x69; // AD0 → 3V3(避开 DS3231 的 0x68)
constexpr uint8_t ADDR_BMP280  = 0x76;
constexpr uint8_t ADDR_DS3231  = 0x68;

// ---------------------------- 可配置参数(NVS 持久化) ----------------------------
struct Params {
  float vOn        = 20.0f;  // km/h,开始张开阈值
  float vFull      = 60.0f;  // km/h,全开速度
  float hyst       = 3.0f;   // km/h,关闭滞回
  float openMaxDeg = 90.0f;  // 全开角硬上限(0=竖直闭合,90=水平全开)
  float slewDegS   = 120.0f; // 开度限斜率 °/s
  int   servoUs0   = 1000;   // 0° 脉宽(装配后标定)
  int   servoUs90  = 2000;   // 90° 脉宽
  int   logHz      = 10;     // 日志频率
};
Params P;
Preferences prefs;

void paramsLoad() {
  prefs.begin("starling", true);
  P.vOn        = prefs.getFloat("vOn",   P.vOn);
  P.vFull      = prefs.getFloat("vFull", P.vFull);
  P.hyst       = prefs.getFloat("hyst",  P.hyst);
  P.openMaxDeg = prefs.getFloat("omax",  P.openMaxDeg);
  P.slewDegS   = prefs.getFloat("slew",  P.slewDegS);
  P.servoUs0   = prefs.getInt("us0",     P.servoUs0);
  P.servoUs90  = prefs.getInt("us90",    P.servoUs90);
  P.logHz      = prefs.getInt("logHz",   P.logHz);
  prefs.end();
}
void paramsSave() {
  prefs.begin("starling", false);
  prefs.putFloat("vOn", P.vOn);   prefs.putFloat("vFull", P.vFull);
  prefs.putFloat("hyst", P.hyst); prefs.putFloat("omax", P.openMaxDeg);
  prefs.putFloat("slew", P.slewDegS);
  prefs.putInt("us0", P.servoUs0); prefs.putInt("us90", P.servoUs90);
  prefs.putInt("logHz", P.logHz);
  prefs.end();
}

// ---------------------------- 状态机 ----------------------------
enum class State { BOOT, ZERO_CAL, RUN, FAULT };
State state = State::BOOT;

float qZeroPa   = 0.0f;   // 静止零偏(上电校准)
float iasKmh    = 0.0f;   // 滤波后指示空速
float qPa       = 0.0f;   // 当前压差(去零偏)
float openDeg   = 0.0f;   // 当前输出开度
int   sensFails = 0;      // 传感连续失败计数(≥25 → FAULT)
bool  logging   = true;
bool  testMode  = false;  // test 命令台架模式
float testDeg   = 0.0f;

BluetoothSerial SerialBT;
File logFile;

// ---------------------------- MS4525DO 读取 ----------------------------
// ±1 psi 差压变体(常见空速计模块):14 位,10%~90% 满码映射 -1..+1 psi
bool ms4525Read(float &pa, float &tC) {
  Wire.requestFrom(ADDR_MS4525, (uint8_t)4);
  if (Wire.available() < 4) return false;
  uint8_t b0 = Wire.read(), b1 = Wire.read(), b2 = Wire.read(), b3 = Wire.read();
  uint8_t status = b0 >> 6;                 // 0=正常 2=陈旧 3=故障
  if (status == 3) return false;
  int16_t praw = ((b0 & 0x3F) << 8) | b1;
  const float PSI_TO_PA = 6894.76f;
  pa = ((praw - 0.1f * 16383.0f) * 2.0f / (0.8f * 16383.0f) - 1.0f) * PSI_TO_PA;
  int16_t traw = ((int16_t)b2 << 3) | (b3 >> 5);
  tC = traw * 200.0f / 2047.0f - 50.0f;
  return true;
}

// ---------------------------- 舵机(LEDC 50Hz) ----------------------------
constexpr int SERVO_CH = 0;
void servoInit() {
  ledcSetup(SERVO_CH, 50 /*Hz*/, 16 /*bit*/);
  ledcAttachPin(PIN_SERVO, SERVO_CH);
}
void servoWriteDeg(float deg) {
  deg = constrain(deg, 0.0f, P.openMaxDeg);           // 软限位(机构另有硬限位)
  float us = P.servoUs0 + (P.servoUs90 - P.servoUs0) * deg / 90.0f;
  uint32_t duty = (uint32_t)(us / 20000.0f * 65535.0f);
  ledcWrite(SERVO_CH, duty);
}

// ---------------------------- 控制律 ----------------------------
// 阈值-斜坡 + 滞回:v>V_ON 起开;回落到 V_ON-HYST 以下才归零(防在阈值附近抖)
float curveTargetPct(float vKmh) {
  static bool armed = false;
  if (!armed) {
    if (vKmh > P.vOn) armed = true; else return 0.0f;
  } else if (vKmh < P.vOn - P.hyst) {
    armed = false; return 0.0f;
  }
  float t = (vKmh - P.vOn) / max(1.0f, P.vFull - P.vOn);
  return constrain(t, 0.0f, 1.0f);
}

void controlStep(float dtS) {
  float tC;
  float paRaw;
  if (ms4525Read(paRaw, tC)) {
    sensFails = 0;
    qPa = paRaw - qZeroPa;
    float q = max(qPa, 0.0f);                          // 负压(软管接反/乱流)按 0
    float v = sqrtf(2.0f * q / 1.225f) * 3.6f;         // IAS km/h,标况密度
    iasKmh += 0.2f * (v - iasKmh);                     // EMA 滤波
  } else if (++sensFails >= 25) {
    state = State::FAULT;                              // 连续失败 → 失效闭合
  }

  float targetDeg = testMode ? testDeg
                             : curveTargetPct(iasKmh) * P.openMaxDeg;
  if (state == State::FAULT) targetDeg = 0.0f;

  float maxStep = P.slewDegS * dtS;                    // 限斜率
  openDeg += constrain(targetDeg - openDeg, -maxStep, maxStep);
  servoWriteDeg(openDeg);
}

// ---------------------------- 传感器套餐(纯记录) ----------------------------
struct Imu { float ax, ay, az, gx, gy, gz, tC; bool ok; };
Imu imuRead() {
  Imu r{}; r.ok = false;
  Wire.beginTransmission(ADDR_MPU6050);
  Wire.write(0x3B);
  if (Wire.endTransmission(false) != 0) return r;
  Wire.requestFrom(ADDR_MPU6050, (uint8_t)14);
  if (Wire.available() < 14) return r;
  auto rd16 = []() { int16_t v = (Wire.read() << 8) | Wire.read(); return v; };
  r.ax = rd16() / 16384.0f; r.ay = rd16() / 16384.0f; r.az = rd16() / 16384.0f;
  r.tC = rd16() / 340.0f + 36.53f;
  r.gx = rd16() / 131.0f;  r.gy = rd16() / 131.0f;  r.gz = rd16() / 131.0f;
  r.ok = true;
  return r;
}
void imuInit() {
  Wire.beginTransmission(ADDR_MPU6050);
  Wire.write(0x6B); Wire.write(0x00);                  // 退出休眠
  Wire.endTransmission();
}

// DS3231:BCD 读时间,给日志文件名与数据行
String rtcNow() {
  Wire.beginTransmission(ADDR_DS3231);
  Wire.write(0x00);
  if (Wire.endTransmission(false) != 0) return "0000-00-00 00:00:00";
  Wire.requestFrom(ADDR_DS3231, (uint8_t)7);
  if (Wire.available() < 7) return "0000-00-00 00:00:00";
  auto bcd = [](uint8_t v) { return (v >> 4) * 10 + (v & 0x0F); };
  int ss = bcd(Wire.read()), mi = bcd(Wire.read()), hh = bcd(Wire.read() & 0x3F);
  Wire.read();                                         // 星期,不用
  int dd = bcd(Wire.read()), mo = bcd(Wire.read() & 0x1F), yy = bcd(Wire.read());
  char buf[24];
  snprintf(buf, sizeof(buf), "20%02d-%02d-%02d %02d:%02d:%02d", yy, mo, dd, hh, mi, ss);
  return String(buf);
}

// TODO(接件时完善):BMP280 需读出厂标定系数做补偿运算,建议直接接 Adafruit_BMP280 库
float bmpPressurePa() { return NAN; }
float bmpTempC()      { return NAN; }

// TODO(接件时完善):GPS NMEA 解析建议接 TinyGPSPlus 库;骨架只开串口
struct Gps { bool fix = false; double lat = 0, lon = 0; float spdKmh = 0; };
Gps gps;
void gpsPoll() {
  while (Serial2.available()) {
    Serial2.read();                                    // TODO:喂给 TinyGPSPlus
  }
}

// ---------------------------- 日志(microSD CSV) ----------------------------
bool sdOk = false;
void logOpen() {
  if (!sdOk) return;
  String ts = rtcNow();
  ts.replace("-", ""); ts.replace(":", ""); ts.replace(" ", "-");
  SD.mkdir("/starling");
  logFile = SD.open("/starling/log-" + ts + ".csv", FILE_WRITE);
  if (logFile)
    logFile.println("ms,rtc,q_pa,ias_kmh,open_pct,servo_deg,"
                    "ax,ay,az,gx,gy,gz,imu_t,baro_pa,baro_t,"
                    "gps_fix,gps_lat,gps_lon,gps_spd_kmh,state");
}
void logStep() {
  if (!logging || !logFile) return;
  Imu m = imuRead();
  char row[256];
  snprintf(row, sizeof(row),
           "%lu,%s,%.1f,%.1f,%.1f,%.1f,%.3f,%.3f,%.3f,%.2f,%.2f,%.2f,%.1f,%.0f,%.1f,%d,%.6f,%.6f,%.1f,%d",
           (unsigned long)millis(), rtcNow().c_str(), qPa, iasKmh,
           openDeg / max(1.0f, P.openMaxDeg) * 100.0f, openDeg,
           m.ax, m.ay, m.az, m.gx, m.gy, m.gz, m.tC,
           bmpPressurePa(), bmpTempC(),
           gps.fix ? 1 : 0, gps.lat, gps.lon, gps.spdKmh, (int)state);
  logFile.println(row);
  static uint32_t lastFlush = 0;
  if (millis() - lastFlush > 1000) { logFile.flush(); lastFlush = millis(); }
}

// ---------------------------- 配置命令台(串口 + 蓝牙共用) ----------------------------
void zeroCal() {
  float sum = 0; int n = 0;
  uint32_t t0 = millis();
  while (millis() - t0 < 2000) {                       // 静止 2s 取均值
    float pa, tC;
    if (ms4525Read(pa, tC)) { sum += pa; n++; }
    delay(10);
  }
  if (n > 50) qZeroPa = sum / n;
}

void handleCmd(Stream &io, String line) {
  line.trim();
  if (line == "help") {
    io.println("help|stat|get|set <k> <v>|save|cal|log on/off|test <deg>|test off|reboot");
  } else if (line == "stat") {
    io.printf("state=%d q=%.1fPa ias=%.1fkm/h open=%.1fdeg sd=%d gps_fix=%d\n",
              (int)state, qPa, iasKmh, openDeg, sdOk ? 1 : 0, gps.fix ? 1 : 0);
  } else if (line == "get") {
    io.printf("vOn=%.1f vFull=%.1f hyst=%.1f openMax=%.0f slew=%.0f us0=%d us90=%d logHz=%d\n",
              P.vOn, P.vFull, P.hyst, P.openMaxDeg, P.slewDegS, P.servoUs0, P.servoUs90, P.logHz);
  } else if (line.startsWith("set ")) {
    int sp = line.indexOf(' ', 4);
    if (sp > 0) {
      String k = line.substring(4, sp); float v = line.substring(sp + 1).toFloat();
      if (k == "vOn") P.vOn = v; else if (k == "vFull") P.vFull = v;
      else if (k == "hyst") P.hyst = v; else if (k == "openMax") P.openMaxDeg = constrain(v, 0.0f, 90.0f);
      else if (k == "slew") P.slewDegS = v; else if (k == "us0") P.servoUs0 = (int)v;
      else if (k == "us90") P.servoUs90 = (int)v; else if (k == "logHz") P.logHz = (int)v;
      else { io.println("未知参数"); return; }
      io.println("ok(save 持久化)");
    }
  } else if (line == "save") {
    paramsSave(); io.println("已保存 NVS");
  } else if (line == "cal") {
    io.println("静止零偏校准 2s..."); zeroCal(); io.printf("zero=%.1fPa\n", qZeroPa);
  } else if (line == "log on")  { logging = true;  io.println("日志开"); }
  else if (line == "log off")   { logging = false; io.println("日志关"); }
  else if (line.startsWith("test")) {
    // ★ §3 边界:test 仅台架(近静止)可用,绝不在骑行中接受外部控制
    if (line == "test off") { testMode = false; io.println("test 退出"); return; }
    if (iasKmh >= 5.0f) { io.println("拒绝:IAS>=5km/h,test 仅限静止台架"); return; }
    testMode = true; testDeg = constrain(line.substring(5).toFloat(), 0.0f, P.openMaxDeg);
    io.printf("test 开度=%.0fdeg\n", testDeg);
  } else if (line == "reboot") { ESP.restart(); }
  else if (line.length()) io.println("未知命令,help 看用法");
}

String bufUsb, bufBt;
void consolePoll(Stream &io, String &buf) {
  while (io.available()) {
    char c = io.read();
    if (c == '\n' || c == '\r') { if (buf.length()) handleCmd(io, buf); buf = ""; }
    else buf += c;
  }
}

// ---------------------------- 主流程 ----------------------------
void setup() {
  Serial.begin(115200);
  SerialBT.begin("Starling-01");                       // 蓝牙 SPP,仅配置+取数
  Wire.begin(PIN_I2C_SDA, PIN_I2C_SCL, 400000);
  Serial2.begin(9600, SERIAL_8N1, PIN_GPS_RX, PIN_GPS_TX);
  paramsLoad();
  servoInit();
  servoWriteDeg(0);                                    // 上电先闭合
  imuInit();
  sdOk = SD.begin(PIN_SD_CS);
  logOpen();
  // TODO:esp_task_wdt 看门狗;BMP280 初始化
  state = State::ZERO_CAL;
  zeroCal();                                           // OQ-4:上电静止零偏
  state = State::RUN;
  Serial.println("Starling 原型一号就绪(help 看命令)");
}

void loop() {
  static uint32_t lastCtl = 0, lastLog = 0;
  uint32_t now = millis();

  if (now - lastCtl >= 20) {                           // 50Hz 控制环
    controlStep((now - lastCtl) / 1000.0f);
    lastCtl = now;
  }
  if (now - lastLog >= (uint32_t)(1000 / max(1, P.logHz))) {
    logStep();
    lastLog = now;
  }
  gpsPoll();
  consolePoll(Serial, bufUsb);
  consolePoll(SerialBT, bufBt);

  if (state == State::FAULT) {                         // 周期重试传感,恢复则回 RUN
    static uint32_t lastRetry = 0;
    if (now - lastRetry > 2000) {
      float pa, tC;
      if (ms4525Read(pa, tC)) { sensFails = 0; state = State::RUN; }
      lastRetry = now;
    }
  }
}

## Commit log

2026-06-25 chore: 初始化 Starling v2 仓库与立项文档
    v1(摩托车主动气动系统)因过度复杂、收益微小而流产。v2 重启为视觉 / 动态件:车头两侧 C 形电子凤翼,随车速张合,不追求下压力。已锁定地基三决策(形态 / 控制 / 名称),立下收益封顶、第一周可观察、禁战线蔓延等铁律。
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2026-06-25 feat: 形态定稿转向百叶式 + 3D 机构示意网页
    经多轮 3D 推演,放弃 3 片折叠方案,转为「固定框 + 多片联动百叶」进气口:低速齐平、高速前缘下斜张开,1 自由度(一舵机经连杆联动),固定框承风。charter §1/§5/§6/§7 更新,OQ-M 解决;新增 proto/wing-3d.html(three.js 交互示意)。
2026-06-25 docs: 记录百叶版暂停点 + §8 后续 GSX250R 高仿真计划
    厘清气流方向(前缘下斜→气流上偏→微下压力,非升力);标记 2026-06-25 暂停点;新增 §8 后续真实 GSX250R 高仿真网页模型计划(待 owner 拍板启动)。
2026-06-26 feat: GSX250R 高仿真网页模型第一稿 + 文档同步百叶式
    - 新建 proto/gsx250r-vreal.html:贴近 GSX250R 车头比例的体块(全整流罩鼻锥/竖排双头灯/熏黑风挡/前挡泥板/前叉/前轮碟盘/后视镜)+ 一对百叶进气口落位到车头两侧(固定框 + 4 片 cambered 翼型薄片联动 + NACA 内凹腔观感),低速齐平/高速张开,1 自由度。交互:车速→开度滑杆 / orbit / 5 视角预设 / 自动播放。
    - 验证:真实浏览器引擎加载,THREE/WebGL OK、脚本跑通、滑杆 readout 0→全开联动正确;修复 three.js Object3D.position 只读坑(Object.assign→at() 助手)。
    - charter §7/§8 记录 §8 高仿真第一稿落地与下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
2026-06-26 fix: 修正百叶开合方向(前缘下斜→迎面风上导出=下压力)+ 加深风道
    按 owner 反馈纠两处与昨日结论不符:
    - 开合方向初版做反了(张开变前缘上抬→把风下导=升力·危险)→ 改为前缘(下缘)下斜、后缘上抬,迎面风打上表面被向上导出→车身微下压力(绝不升力)。SLAT 角度由 +4/+56° 改为 -6/-58°(负角=绕下缘转、上缘后掀进风道)。
    - 风道太浅(薄薄一层)→ 深度 0.16→0.42,内凹腔由后壁+上/下/左/右四面内壁组成真实深腔。
    - 加 window.__starlingProbe 探针:无头环境数值验证开启时下缘在前/在下、上缘在后/在上(frontLowerAndForward=true),不靠截图。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
2026-06-26 fix: 百叶角度按 owner 规格——初始竖直(0°)/张开到顶 -45°
    - SLAT 角 -6/-58° → 0/-45°(初始叶片竖直封口·张开前缘下斜 45°)。
    - 竖直闭合改为略重叠(chord×1.12)+ 微 z 错层防 z-fighting。
    - 探针实测:闭合前后缘等 z(纯竖直)、全开弦线偏竖直 45° 且 frontLowerAndForward=true;readout 闭合(竖直)/全开(-45°)。
    - charter §7 记录角度规格 + 速度→角度曲线归 OQ-5;页面图例/说明同步。
2026-06-26 fix: 百叶开合方式按 owner 草图——绕上缘外掀、下缘凸出车体(鳃片式)
    初版张开是叶片往里缩进风道,与 owner 手绘相反。改为:
    - 铰链移到上缘(geo.translate -chord/2),负角时下缘向外掀出、凸出车体表面(像鳃片/scoop),露出身后深腔。
    - 闭合仍竖直贴面齐平;开度仍 0°→45°。
    - 探针重写:实测全开 下缘 z 0.008→0.107(凸出·protrudesOut)、迎风外法线 Y=0.707(朝上·deflectsUp)→ 风上导=下压力;闭合中性。
    - charter §7 记录草图开合方式;页面说明改为"绕上缘外掀/下缘凸出/露深腔"。
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2026-06-26 feat: glTF 真车加载器 + 百叶动效清晰化(进气口特写/高对比/橙缘)
    车体走路线 A(导入真实模型),并解决"动效看不清":
    - glTF 加载器:THREE.GLTFLoader(jsdelivr UMD),拖入 .glb/.gltf 即加载 或 ?model=URL;auto-fit 缩放居中落地 + 隐藏占位体块;Khronos 样本 GLB 远程验证加载/解析全通。
    - 进气口独立成 intakeRig 组(换真车后整体重定位)。
    - 动效清晰化:进气口加大、亮银蓝叶片 + 橙色自由(下)缘描边、深腔更黑、新增"进气口特写"默认视角(NDC 实测右进气口居中)、滚轮缩放、自动播放放慢+两端停顿+默认开启。
    - charter §7/§8 记录路线 A 与待 owner 提供 .glb;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
2026-06-26 feat: 按真实尺寸重建整车 GSX250R + 收集尺寸资料
    owner 要"完全仿真整车,先收集资料建模":
    - docs/gsx250r-reference.md:官方实测尺寸(总长2085/宽740/高1110/轴距1430/座高790mm)、轮胎(前110/80-17 R304、后140/70-17 R314)、17"十辐、整流罩散热逻辑(鳃口落位依据)、建模坐标表 + 来源。
    - proto/gsx250r-vreal.html 整车按真实尺寸重建(SPEC 驱动 1unit=1m):前后两轮(正确半径/胎宽/轴距)+前叉/后摇臂/避震/引擎/排气/油箱/座/尾/全包整流罩/竖排双头灯/熏黑风挡/挡泥板/后视镜/把手;进气口真实比例落上侧整流罩。
    - 实测对齐:内禀高 1.11m(=真车1.110)、长2.05m(真车2.085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
2026-06-27 feat: 风洞气流可视化(示意流线+粒子·非CFD解算)
    owner 要"风洞模拟效果务必真实":已明言真 CFD 在单文件网页不可行/超边界,改做风洞式气流可视化:
    - 启发式流场 fieldVel:来流 -Z + 车体绕流(Rankine 源-汇)+ 百叶上导(每侧进气口局部上向速度随开度增强)。
    - 30 条静态流线(暖色=被明显上导)+ 1400 流动粒子(live 烟流)+ 测试段框;"🌫 风洞气流"按钮切换、随车速滑杆联动。
    - 数值验证 __starlingFlowCheck:右进气口流线最高 y 闭合 1.004→全开 1.169(+16.5cm 上导),如实呈现"百叶张开→风上导=下压力"随开度增强;无报错。
    - 界面明确标注"非 CFD、仅机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
2026-06-27 feat: 气动取舍选 B——高速叶片放平羽化(低阻,不要下压力)
    owner 拍板:百叶"斜着导流出下压力"与"放平羽化低阻"不可兼得,且下压力可忽略 → 选低阻。
    - 全开角 -45° → -90°(竖直闭合→水平羽化/顺气流=低阻通风口),放弃下压力叙事。
    - 风洞流场:偏流强度=sin(开度×π)(0°与90°皆0、~45°最大)→ 全速放平流线顺流穿过不再上挑。
    - 验证:右进气口流线最高 y 闭合1.004/中途1.169/全速1.004(0偏流=低阻);无报错。
    - 页面读数/说明 + charter 叙事同步。
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2026-06-27 fix: 百叶改绕中轴转(威尼斯式)——消除高速向前凸出的错觉
    owner 反馈"看着像低速放平/高速垂直":根因是叶片绕上缘转→高速水平时向前凸出 0.07m(像鳃片探出),贴面的竖直态反而像"放平"。
    - 改绕中心转(去掉 geo.translate):低速竖直贴面、高速水平居中,凸出 0.07→0.039 且不再向前探出 → 读作干净的"竖直→放平",也才真低阻。
    - 探针采样改 ±chord/2;橙色缘移到 -chord/2。验证:低速竖直/高速水平、低阻不变(flow_full_lift=0)、无报错。
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2026-06-27 fix: 百叶可读性大改——平薄片/去镜面/删橙黄描边/去楼梯错层
    owner 截图反馈"黄灰叶片看不懂":根因=弧度+镜面让薄片看着像银色圆柱、橙色自由缘条又粗又亮抢眼、z错层+梯形收窄叠成楼梯。
    - 叶片改 thin box 平薄片(去 camber)、材质改哑光浅银(roughness0.62/metalness0.12,不反光成圆柱)。
    - 删掉橙色自由缘描边条(MAT.edge)+图例项。
    - 去 z 错层(s.position.z=0)、chord 0.94 留细缝 → 干净竖直堆叠,不叠楼梯。
    - 进气口特写相机拉远(camDist 1.15→1.75)露出整个鳃口。
    - 验证:低速竖直/高速水平(屏幕实测)、无报错。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
2026-06-27 fix: 视觉降噪——头灯改小六角投射(去"呆萌大白圆")+ 百叶降到中灰不过曝 + 主光降一档
    通过浏览器直连首次实际看到渲染:头灯是两个大白圆(呆萌)、百叶过曝成纯白、整体偏亮。
    - MAT.head 降亮(emissiveIntensity 0.9→0.28)+ 头灯缩小成小六角(r0.07→0.05·6边)嵌入黑灯罩。
    - MAT.slat 中灰蓝(0xc6d2e2→0x9aa4b6)不过曝、见明暗读出平板。
    - 主光 0.95→0.70 防过曝。
2026-06-27 feat: 接入真实车体模型(Sports Bike CC-BY)+ 鳃口落到前整流罩侧面
    路线 A 落地:
    - 加载器默认加载 res/sports_bike(scene.gltf,经静态服务器),fitModel 自动缩放居中落地、隐藏占位方块;?model= / 拖拽可换车型。
    - 鳃口落位 GILL_ON_BIKE{iy0.80,iz0.78,scale0.48,spread0.19,ry0.45}(浏览器实测调出·+z=车头),showModel 加载后自动落到前整流罩侧面。
    - 视觉降噪:头灯小六角/百叶哑光中灰/主光降档(前几次提交)。
    - CC-BY-4.0 署名 Futurealiti(页面+README+charter+license.txt)。
2026-06-27 fix: 修鳃口左右朝向(toe-out反了)+ 框倒角(bevel)更流线 + 收紧落位
    owner 反馈"只有单侧 + 要倒角更流线":
    - 只有单侧=3/4 视角遮挡 + 落位时左右 toe-out 写反(远侧朝向错)→ 修为 左 -ry/右 +ry,正视确认两侧对称朝外。
    - 框改 ExtrudeGeometry bevelEnabled(bevelThickness0.012/Size0.009/2段)→ 边缘倒角、更流线不那么像盒子。
    - GILL_ON_BIKE 收紧 spread0.19→0.165/scale0.48→0.46/iz0.78→0.76 → 更贴前整流罩侧颊。
2026-06-28 fix: 修复鳃口被车壳遮挡问题，改为射线吸附落位，确保与车体模型自动贴合
2026-06-28 fix: 调整进气口聚焦位置和落位参数，确保与车体模型更好贴合
2026-06-28 fix: 更新鳃口描述为迎风进气口，调整落位和开口方向以符合车身设计
2026-06-28 fix: 更新文档描述，明确鳃口位置和开口方向为车身侧板、朝车头迎风
2026-06-28 fix: 删除不再使用的3D进气口示意HTML文件
2026-06-28 fix: 更新3D模型材质和结构，优化进气口设计以提升视觉效果和气流通透性
2026-06-28 fix: 优化进气口模型，调整尺寸和形状以提升气流效率和视觉效果
2026-06-28 fix: 调整进气口模型参数，优化标签显示和交互效果
2026-06-28 fix: 调整进气口模型的缩放参数和开口朝向，以优化气流效果和视觉表现
2026-06-28 fix: 优化进气口模型参数，调整尺寸和形状以提升气流效率和视觉效果
2026-06-28 fix: 优化进气口模型，调整翼片和下缘设计以适应深度变化，提升气流效率和视觉效果
2026-06-28 fix: 优化进气口模型，调整前脸薄口框和进气道参数以提升气流效率和视觉效果
2026-06-28 公开化:补 GPL-3.0 协议 + 完善 README/.gitignore
    新增 LICENSE(GPL-3.0);res/sports_bike 第三方 CC-BY 模型不受本仓库 GPL 覆盖;README 增许可说明;.gitignore 补依赖/缓存/工具临时项。
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2026-07-02 feat: add initial version of Starling prototype documentation and firmware
    - Introduced the prototype v1 specifications document detailing objectives, BOM, wiring, power budget, mechanical specifications, firmware design, assembly steps, and safety measures.
    - Implemented the firmware skeleton for the Starling prototype, including state machine, control logic, sensor reading, logging, and command handling.
    - Established configuration parameters with NVS persistence and integrated Bluetooth and USB command interfaces for configuration and data retrieval.
2026-07-02 采购清单零烙铁审核:res/prototype-v1-采购清单.xlsx(台架37项+阶段二+PCB方案)
    - 免焊三原则:模块选已焊排针/杜邦·端子·WAGO 连接/需焊集中到定制底板由板厂焊
    - 关键增补:GH转杜邦线(4525套装为GH座)·ESP32 38P端子扩展板·DS3231 LIR2032版·M2球头拉杆+易拉夹
    - 舵机 EMAX ES3054 规格查证坐实;合计=必买¥615/全部¥826(Excel重算零公式错误)
    - PCB 结论:台架不打板;装车做模块底板(嘉立创贴片+插件焊),不做芯片级全集成
    - prototype-v1.md 与 charter §7 同步
    [prototype-v1-采购清单.xlsx]
2026-07-02 feat: 添加 Starling 原型一号机构参数化模型 v0.1 的 OpenSCAD 源文件
    [starling_v1.scad]
2026-07-02 Refactor code structure for improved readability and maintainability
    [blade.stl, crank.stl, frame.stl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]
2026-07-02 机构 CAD v0.1:参数化 OpenSCAD 源 + 6 件台架 STL + 装配文档
    - cad/starling_v1.scad = 唯一 CAD 真相(舵机/轴径等关键尺寸参数化,到货复测后改参重渲)
    - 零件:固定框/叶片×4/曲柄×4/拉杆/舵机支架/台架座;威尼斯百叶中轴转+平行四边形联动+扭簧常闭
    - 落地修正:闭合角=10°微倾鳞片搭接(0°竖直相邻叶尖干涉)·内腔高56→60(叶尖扫掠间隙)
    - 验证:6 STL 全水密+包围盒符合;正交渲染=闭合满窗遮蔽/全开水平露缝/曲柄拉杆随动正确
    - cad/README.md:打印姿态/金属下料/8步装配/固件标定映射/★到货复测参数表
    [frame.stl, starling_v1.scad]
2026-07-02 cad/dist 打印农场交付包:按打印姿态摆好的带数量 STL + 下单说明 + zip
    - 6 件 STL 重摆落床(叶片翻转凸面朝下背脊槽朝上·舵机支架放平)全水密验证
    - 下单说明.txt:FDM/PLA+·1:1 勿缩放·孔径已含补偿勿扩·逐件填充/支撑/备件数·验收标准
    - 修正 cad/README:叶片弧形底需两翼支撑(原"免支撑"不成立)·前脸悬檐备注·dist 用途说明
    [01_frame_x1.stl, 02_blade_x4.stl, 03_crank_x4.stl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]
2026-07-02 材料改线:直接全上 PA12(-CF) 粉末尼龙,dist 交付包重做为 v0.2
    - owner 拍板跳过 PLA 台架批;叶片 PA12 勿 CF(薄壁要韧),框/支架可 PA12-CF;PETG 路线作废
    - dist STL 以 HOLE_COMP=0.1(粉末工艺)重出+重打包;下单说明 v0.2 按 MJF/SLS 重写(FDM 备选段保留)
    - 连带变更:装配胶 CA→环氧 AB(尼龙粘不住 502);采购清单加环氧行(必买¥625)+PETG 降为可选,Excel 重算零错误
    - cad/README 材料路线/下料/装配步骤同步
    [01_frame_x1.stl, 02_blade_x4.stl, 03_crank_x4.stl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]
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2026-08-21 新增文档：更新 AGENTS.md，添加代理技能部分；新增 issue-tracker.md、domain.md、skill-workflows.md 和 triage-labels.md，提供相关工作流程和标签说明
2026-08-21 新增文档：添加文档系统、领域文档、问题跟踪器、技能工作流程和分类标签的说明，完善项目知识体系
2026-08-21 更新文档：在 domain.md、issue-tracker.md、skill-workflows.md 和 triage-labels.md 文件中添加空行，以提高可读性
2026-08-31 docs: bring AGENTS.md under the 8 KiB workspace context budget
    The workspace now imports every project's AGENTS.md into each session
    through a CLAUDE.md shim, so its size is charged to the resident context
    of every task in this repo. nxtplan.md N07/section 4 caps a project
    guideline at 8 KiB and 150 lines.
    Deletion followed nxtplan.md N02: a rule may only be removed when some
    other thing goes red without it (a gate, a test, a hard-validating tool),
    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
2026-09-01 docs: 收敛为 OKF v0.2 bundle
    按工作区的 OKF v0.2 契约（`Docs/agents/documentation.md`）把 `docs/` 收敛到位。
    - `docs/index.md`：补上 bundle 入口 / 声明 okf_version
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2026-09-09 docs(agents): triage 标签映射改成实况 —— 四个角色本工作区不发布
    原文把五个 canonical triage 角色一对一映射到同名标签，并在末行要求
    「Edit the right-hand column to match whatever vocabulary you actually use」。
    2026-09-09 逐仓实测，那张表**四行是假的**。
    ## 读数
    | 量的东西 | 结果 |
    |---|---|
    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
